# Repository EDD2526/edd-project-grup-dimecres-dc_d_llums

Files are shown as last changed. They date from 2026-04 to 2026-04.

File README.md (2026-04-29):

# Projecte Llums Cotxe

> **Autors:** Marcel Lleonart, Eric Ruiz, Josep Leyva
> **Versió:** 1.1
> **Eina de disseny:** KiCad 9.0 o superior

---

##  Objectiu

Desenvolupar un **sistema de control de llums per a un automòbil a escala de projecte**, gestionat mitjançant un microcontrolador. El sistema integra els principals subsistemes d'il·luminació d'un vehicle i permet el seu control manual i automàtic.

### Funcions principals

* Llums diürnes (**DRL**)
* Intermitents esquerre i dret
* Llums de creuament
* Llums de carretera
* Activació automàtica segons la llum ambiental

Cada canal incorpora:

* Etapa de potència amb MOSFET
* Resistència de gate i pull-down
* Control directe des del microcontrolador mitjançant GPIO

---

##  Diagrama de blocs

<p align="center">
  
</p>

---

##  Descripció funcional dels blocs

###  Microcontrolador – PIC18F26Q83

Coordina tots els subsistemes de llum, processa les entrades dels sensors i gestiona les comunicacions externes. Disposa d'interfícies **CAN**, **I2C** i **USART** per a expansió, diagnosi i depuració.

###  Driver de llums diürnes (DRL)

Controla l'encesa automàtica de les llums diürnes mitjançant un MOSFET **AO3400A**. L'activació es realitza segons la lectura del sensor de llum ambiental.

###  Driver d'intermitents

Gestiona els intermitents esquerre i dret. El parpelleig es genera per programari utilitzant temporitzadors interns del microcontrolador.

###  Driver de llums de creuament

Permet el control ON/OFF de les llums de creuament amb protecció elèctrica individual.

###  Driver de llums de carretera

Controla les llums de carretera amb protecció mitjançant fusible. Compatible amb càrregues LED o halògenes de baixa potència.

### Sensor de llum ambiental

Mesura la il·luminació exterior i permet l'activació automàtica de les llums diürnes o altres funcions programades.

---

##  Especificacions tècniques

| Paràmetre | Valor |
| --- | --- |
| Alimentació principal  | 12 Vcc |
| Alimentació lògica | 3.3 V regulats |
| Microcontrolador | Pic24hj128gp502 |
| Comunicacions | CAN, I2C, USART |
| MOSFET de potència | AO3400A (canal N, logic-level) |
| Nivell de control GPIO | 3.3 V |
| Protecció |resistència de gate + pull-down |

---

##  Assignació de GPIO

| Senyal | Funció |
| --- | --- |
| `DRL_CTRL` | Control de llums diürnes |
| `TURN_LEFT_CTRL`  | Intermitent esquerre |
| `TURN_RIGHT_CTRL` | Intermitent dret |
| `LOW_BEAM_CTRL` | Llums de creuament |
| `HI_BEAM_CTRL` | Llums de carretera |
| `LIGHT_INT` | Interrupció del sensor de llum |

---

##  Funcionalitats implementades

* Activació automàtica de les DRL segons la llum ambiental
* Control independent de llums de creuament i carretera
* Interfície de depuració per USART
* Arquitectura preparada per integració en xarxa CAN

---

##  Llista de materials (BOM)

| Component | Valor / Model | Encapsulat | Quantitat |
| --- | --- | --- | ---: |
| Microcontrolador | Pic24hj128gp502 | SOIC-28 | 1 |
| MOSFET canal N | AO3400A | SOT-23 | 8 |
| Regulador lineal | LM1117-5.0 | TO-252 | 1 |
| Resonador / Cristall | 8 MHz | HC-49 o equivalent | 1 |
| Inductor | 33 µH | Radial | 1 |
| Díodes de protecció | Rectificador | DO-201AD | 9 |
| Condensadors de desacoblament | 100 nF | 0805 | 7 |
| Condensadors | 10 µF | 0805 | 3 |
| Condensador electrolític | 680 µF | Radial | 1 |
| Condensadors | 33 pF | 0805 | 2 |
| Condensador | 4.7 nF | 0805 | 1 |
| Resistències | 100 Ω | 0805 | 8 |
| Resistències | 10 kΩ | 0805 |  Diverses |
| Borns de connexió | 2 vies, pas 5.08 mm | Terminal Block | 11 |
| Connector ICSP | Programació PIC | 2x03, 2.54 mm | 1 |
| Interruptors SPDT | Selector | Through-hole | 5 |
| Polsador | Reset / funció | 6 mm | 1 |
| Sensor de llum | TSL2561 (o equivalent I2C) | SMD | 1 |

> **Nota:** La quantitat exacta d'alguns components passius pot variar segons la revisió del disseny i les opcions de muntatge.

---

##  Programació i configuració

### Perifèrics utilitzats

* GPIO digitals per al control de sortides
* I2C per al sensor de llum
* USART per a depuració i diagnosi
* CAN per a futures ampliacions

---

##  Proteccions incorporades

* Resistència sèrie a la gate dels MOSFET
* Resistència pull-down per evitar activacions espúries
* Filtrat de l'alimentació mitjançant condensadors de desacoblament
* Protecció davant transitoris de commutació

---

##  Aplicacions

Aquest projecte és ideal per a:

* Maquetes i prototips d'automoció
* Sistemes d'il·luminació intel·ligents
* Pràctiques de microcontroladors i electrònica de potència
* Desenvolupament de mòduls electrònics per automoció

---

##  Estat del projecte

**Versió actual:** 1.5

* ✅ Esquemàtic completat
* 🔄 PCB en desenvolupament i validació
* ✔️ BOM inicial verificada

---

##  Llicència

Aquest projecte ha estat desenvolupat amb finalitats educatives i acadèmiques.

---

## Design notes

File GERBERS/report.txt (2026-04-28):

Aviso: Corrección del ancho restringida. El valor de la corrección del ancho debe encontrarse en el rango de [-0,149999 mm; -0,000002 mm] para las reglas de diseño actuales.
Plotted to 'C:\Users\User\Desktop\Grup_D_Llums-F_Cu.gbr'.
Plotted to 'C:\Users\User\Desktop\Grup_D_Llums-B_Cu.gbr'.
Plotted to 'C:\Users\User\Desktop\Grup_D_Llums-F_Paste.gbr'.
Plotted to 'C:\Users\User\Desktop\Grup_D_Llums-B_Paste.gbr'.
Plotted to 'C:\Users\User\Desktop\Grup_D_Llums-F_Silkscreen.gbr'.
Plotted to 'C:\Users\User\Desktop\Grup_D_Llums-B_Silkscreen.gbr'.
Plotted to 'C:\Users\User\Desktop\Grup_D_Llums-F_Mask.gbr'.
Plotted to 'C:\Users\User\Desktop\Grup_D_Llums-B_Mask.gbr'.
Plotted to 'C:\Users\User\Desktop\Grup_D_Llums-Edge_Cuts.gbr'.
Created Gerber job file 'C:\Users\User\Desktop\Grup_D_Llums-job.gbrjob'.
Info: Done.
Info: Done.

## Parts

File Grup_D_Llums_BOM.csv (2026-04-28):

Id | Identificador | Huella | Cantidad | Identificación | Suministrador y ref
1 | C11,C13,C10 | C_0805_2012Metric | 3 | 10 uF
2 | R17,R19,R3,R9,R2,R7,R15,R5 | R_0805_2012Metric | 8 | 100
3 | J12,J7,J6,J11,J10,J13,J8,J2,J14,J3,J9 | TerminalBlock_Phoenix_MKDS-1,5-2-5.08_1x02_P5.08mm_Horizontal | 11 | Screw_Terminal_01x02
4 | J4 | PinHeader_2x03_P2.54mm_Vertical | 1 | Conn_PIC_ICSP_ICD
5 | Q6,Q4,Q8,Q2,Q3,Q5,Q7,Q1 | SOT-23 | 8 | AO3400A
6 | C8,C6,C2,C5,C7 | C_0805_2012Metric | 5 | 100 nF
7 | L1 | L_Radial_D10.0mm_P5.00mm_Fastron_07M | 1 | 33 U
8 | C16,C4 | C_0805_2012Metric | 2 | 100nF
9 | SW2,SW6,SW4,SW5,SW3 | SW_SPDT_CK_JS102011SAQN | 5 | SW_SPDT
10 | C9 | CP_Radial_D10.0mm_P5.00mm | 1 | 680 uF
11 | Y2 | Crystal_HC49-U_Vertical | 1 | Crystal
12 | D5,D3,D7,D11,D9,D10,D6,D8,D12 | D_DO-201AD_P15.24mm_Horizontal | 9 | D
13 | SW7 | SW_PUSH_6mm | 1 | SW_SPST
14 | C14,C17 | C_0805_2012Metric | 2 | 33pF
15 | C3 | C_0805_2012Metric | 1 | 4.7 nF
16 | U7 | TO-252-3_TabPin2 | 1 | LM1117DT-3.3
17 | R8,pull_FC1,pull_INT1,R4,R18,R20,R16,R1,R14,R6,R10 | R_0805_2012Metric | 11 | 10k
18 | J1,J5 | DSUB-9_Socket_Horizontal_P2.77x2.84mm_EdgePinOffset9.40mm | 2 | DE9_Pins
19 | U9 | Rohm_RPR-0521RS | 1 | RPR-0521RS
20 | U2 | TO-263-5_TabPin3 | 1 | LM2596S-5
21 | U6 | SOIC-8_3.9x4.9mm_P1.27mm | 1 | SN65HVD232
22 | U3 | TO-220-15_P2.54x5.08mm_StaggerOdd_Lead4.58mm_Vertical | 1 | L298N
23 | D2 | LED_0805_2012Metric | 1 | LED
24 | C1 | CP_Radial_D8.0mm_P3.50mm | 1 | 220 uF
25 | pull_SCL2,pull_SDA2 | R_0805_2012Metric | 2 | 4k7
26 | R11 | R_0805_2012Metric | 1 | 1k
27 | U1 | TQFP-44_10x10mm_P0.8mm | 1 | PIC32MX250F128D-IPT
28 | R12,R13 | R_0603_1608Metric | 2 | 60 Ω
29 | SW1 | SW_Push_1P1T-SH_NO_CK_KMR2xxG | 1 | SW_Push
30 | D4,D1 | D_DO-201AD_P15.24mm_Horizontal | 2 | 1N5822

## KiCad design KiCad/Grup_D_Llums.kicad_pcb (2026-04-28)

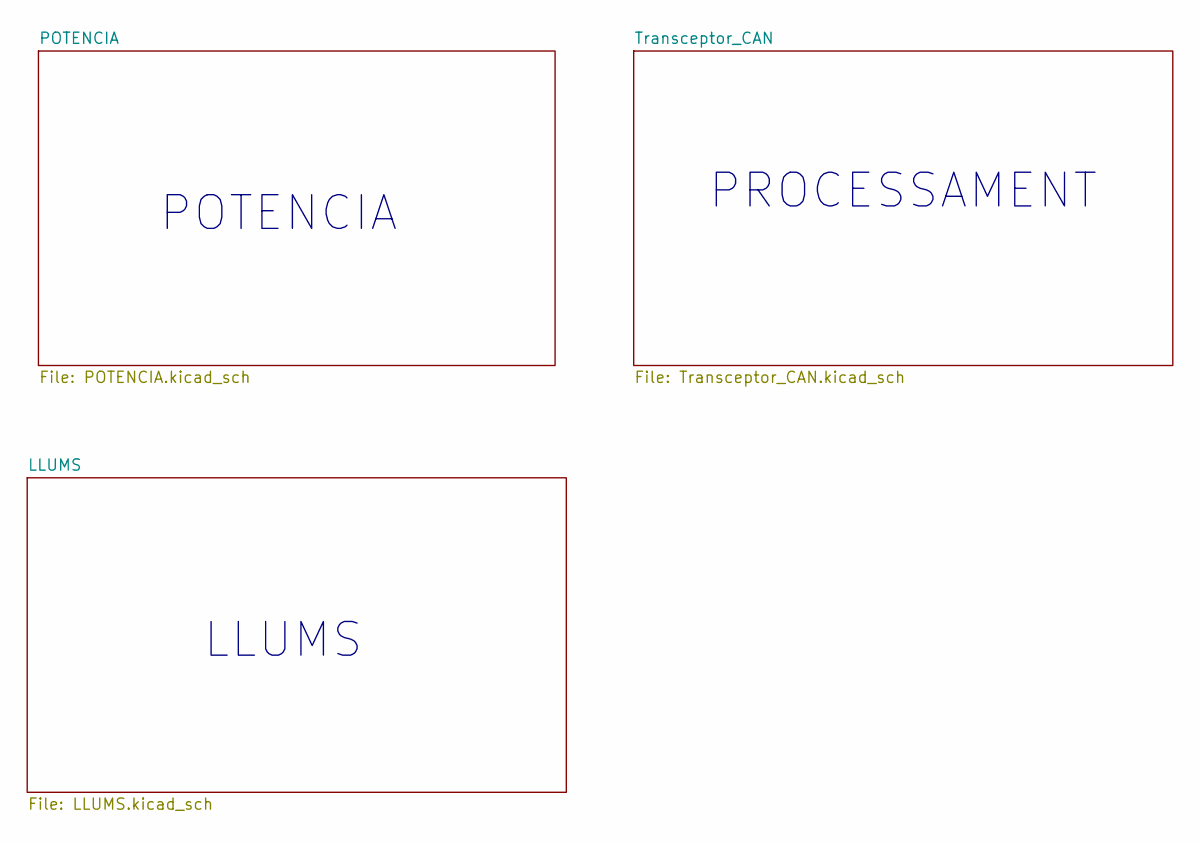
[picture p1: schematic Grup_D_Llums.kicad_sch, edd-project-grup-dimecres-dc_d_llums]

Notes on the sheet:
PROCESSAMENT
LLUMS
POTENCIA

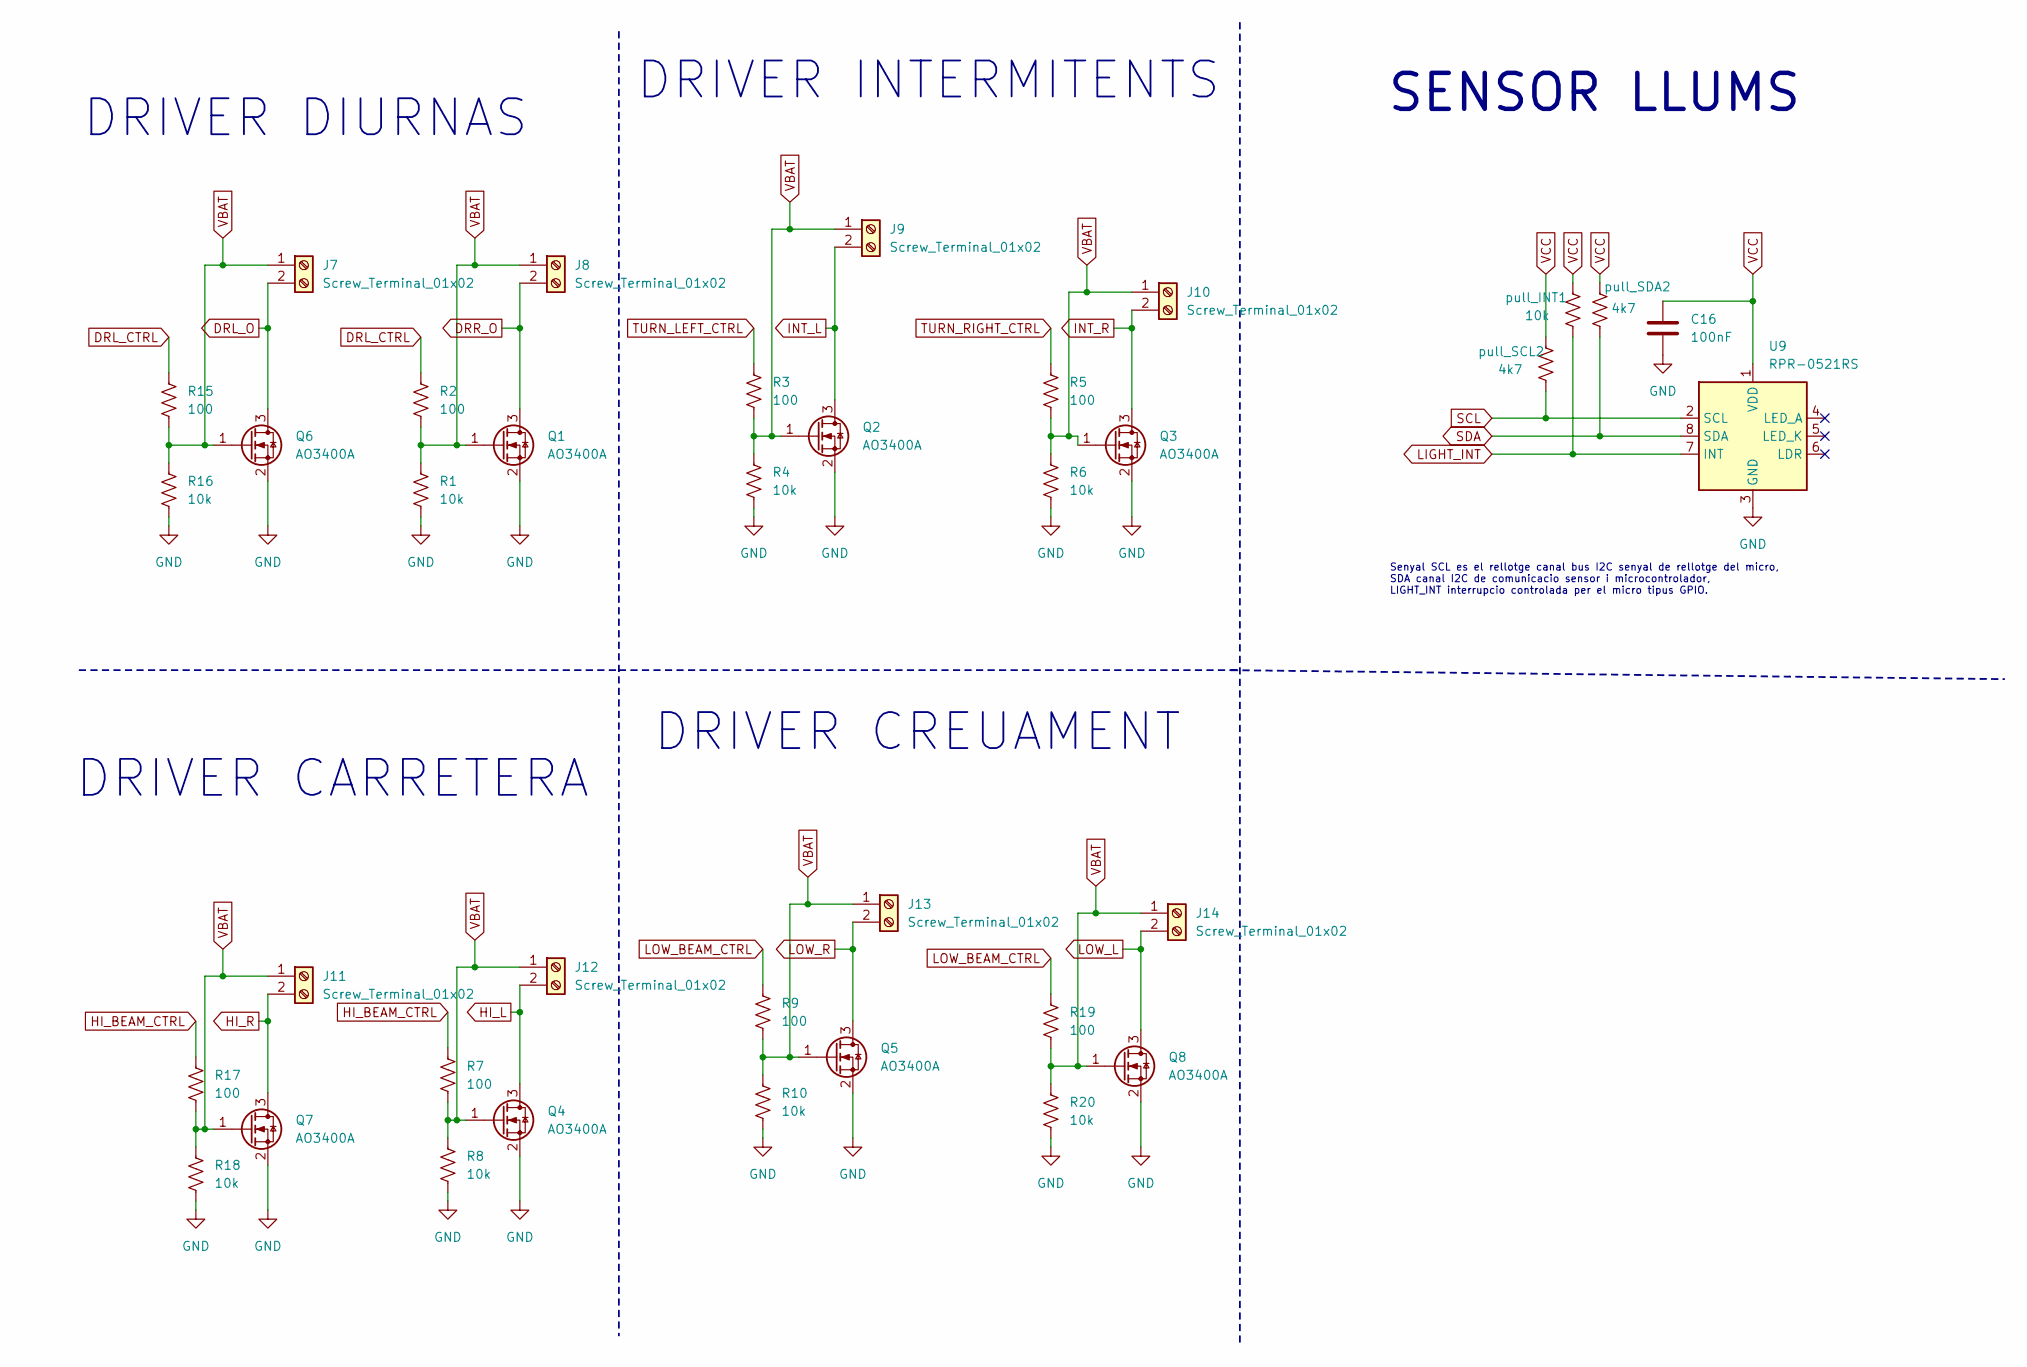
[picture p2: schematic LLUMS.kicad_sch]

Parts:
C16: 100nF; C_0805_2012Metric
J7, J8, J9, J10, J11, J12, J13, J14: Screw_Terminal_01x02; TerminalBlock_Phoenix_MKDS-1,5-2-5.08_1x02_P5.08mm_Horizont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
Q1, Q2, Q3, Q4, Q5, Q6, Q7, Q8: AO3400A; SOT-23
R1, R4, R6, R8, R10, R16, R18, R20: 10k; R_0805_2012Metric
R2, R3, R5, R7, R9, R15, R17, R19: 100; R_0805_2012Metric
U9: RPR-0521RS; Rohm_RPR-0521RS
pull_INT1: 10k; R_0805_2012Metric
pull_SCL2: 4k7; R_0805_2012Metric
pull_SDA2: 4k7; R_0805_2012Metric

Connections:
DRL_CTRL: R2.1, R15.1; also elsewhere on the board
DRL_O: J7.2, Q6.3 (D)
DRR_O: J8.2, Q1.3 (D)
GND: C16.2, Q1.2 (S), Q2.2 (S), Q3.2 (S), Q4.2 (S), Q5.2 (S), Q6.2 (S), Q7.2 (S), Q8.2 (S), R1.2, R4.2, R6.2, R8.2, R10.2, R16.2, R18.2, R20.2, U9.3 (GND); also elsewhere on the board
HI_BEAM_CTRL: R7.1, R17.1; also elsewhere on the board
HI_L: J12.2, Q4.3 (D)
HI_R: J11.2, Q7.3 (D)
INT_L: J9.2, Q2.3 (D)
INT_R: J10.2, Q3.3 (D)
LIGHT_INT: U9.7 (INT), pull_INT1.2; also elsewhere on the board
LOW_BEAM_CTRL: R9.1, R19.1; also elsewhere on the board
LOW_L: J14.2, Q8.3 (D)
LOW_R: J13.2, Q5.3 (D)
SCL: U9.2 (SCL), pull_SCL2.2; also elsewhere on the board
SDA: U9.8 (SDA), pull_SDA2.2; also elsewhere on the board
TURN_LEFT_CTRL: R3.1; also elsewhere on the board
TURN_RIGHT_CTRL: R5.1; also elsewhere on the board
VBAT: J7.1, J8.1, J9.1, J10.1, J11.1, J12.1, J13.1, J14.1, Q1.1 (G), Q2.1 (G), Q3.1 (G), Q4.1 (G), Q5.1 (G), Q6.1 (G), Q7.1 (G), Q8.1 (G), R1.1, R2.2, R3.2, R4.1, R5.2, R6.1, R7.2, R8.1, R9.2, R10.1, R15.2, R16.1, R17.2, R18.1, R19.2, R20.1; also elsewhere on the board
VCC: C16.1, U9.1 (VDD), pull_INT1.1, pull_SCL2.1, pull_SDA2.1; also elsewhere on the board

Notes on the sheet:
DRIVER INTERMITENTS
SENSOR LLUMS
DRIVER CREUAMENT
DRIVER DIURNAS
DRIVER CARRETERA
Senyal SCL es el rellotge canal bus I2C senyal de rellotge del micro, SDA canal I2C de comunicacio sensor i microcontrolador, LIGHT_INT interrupcio controlada per el micro tipus GPIO.

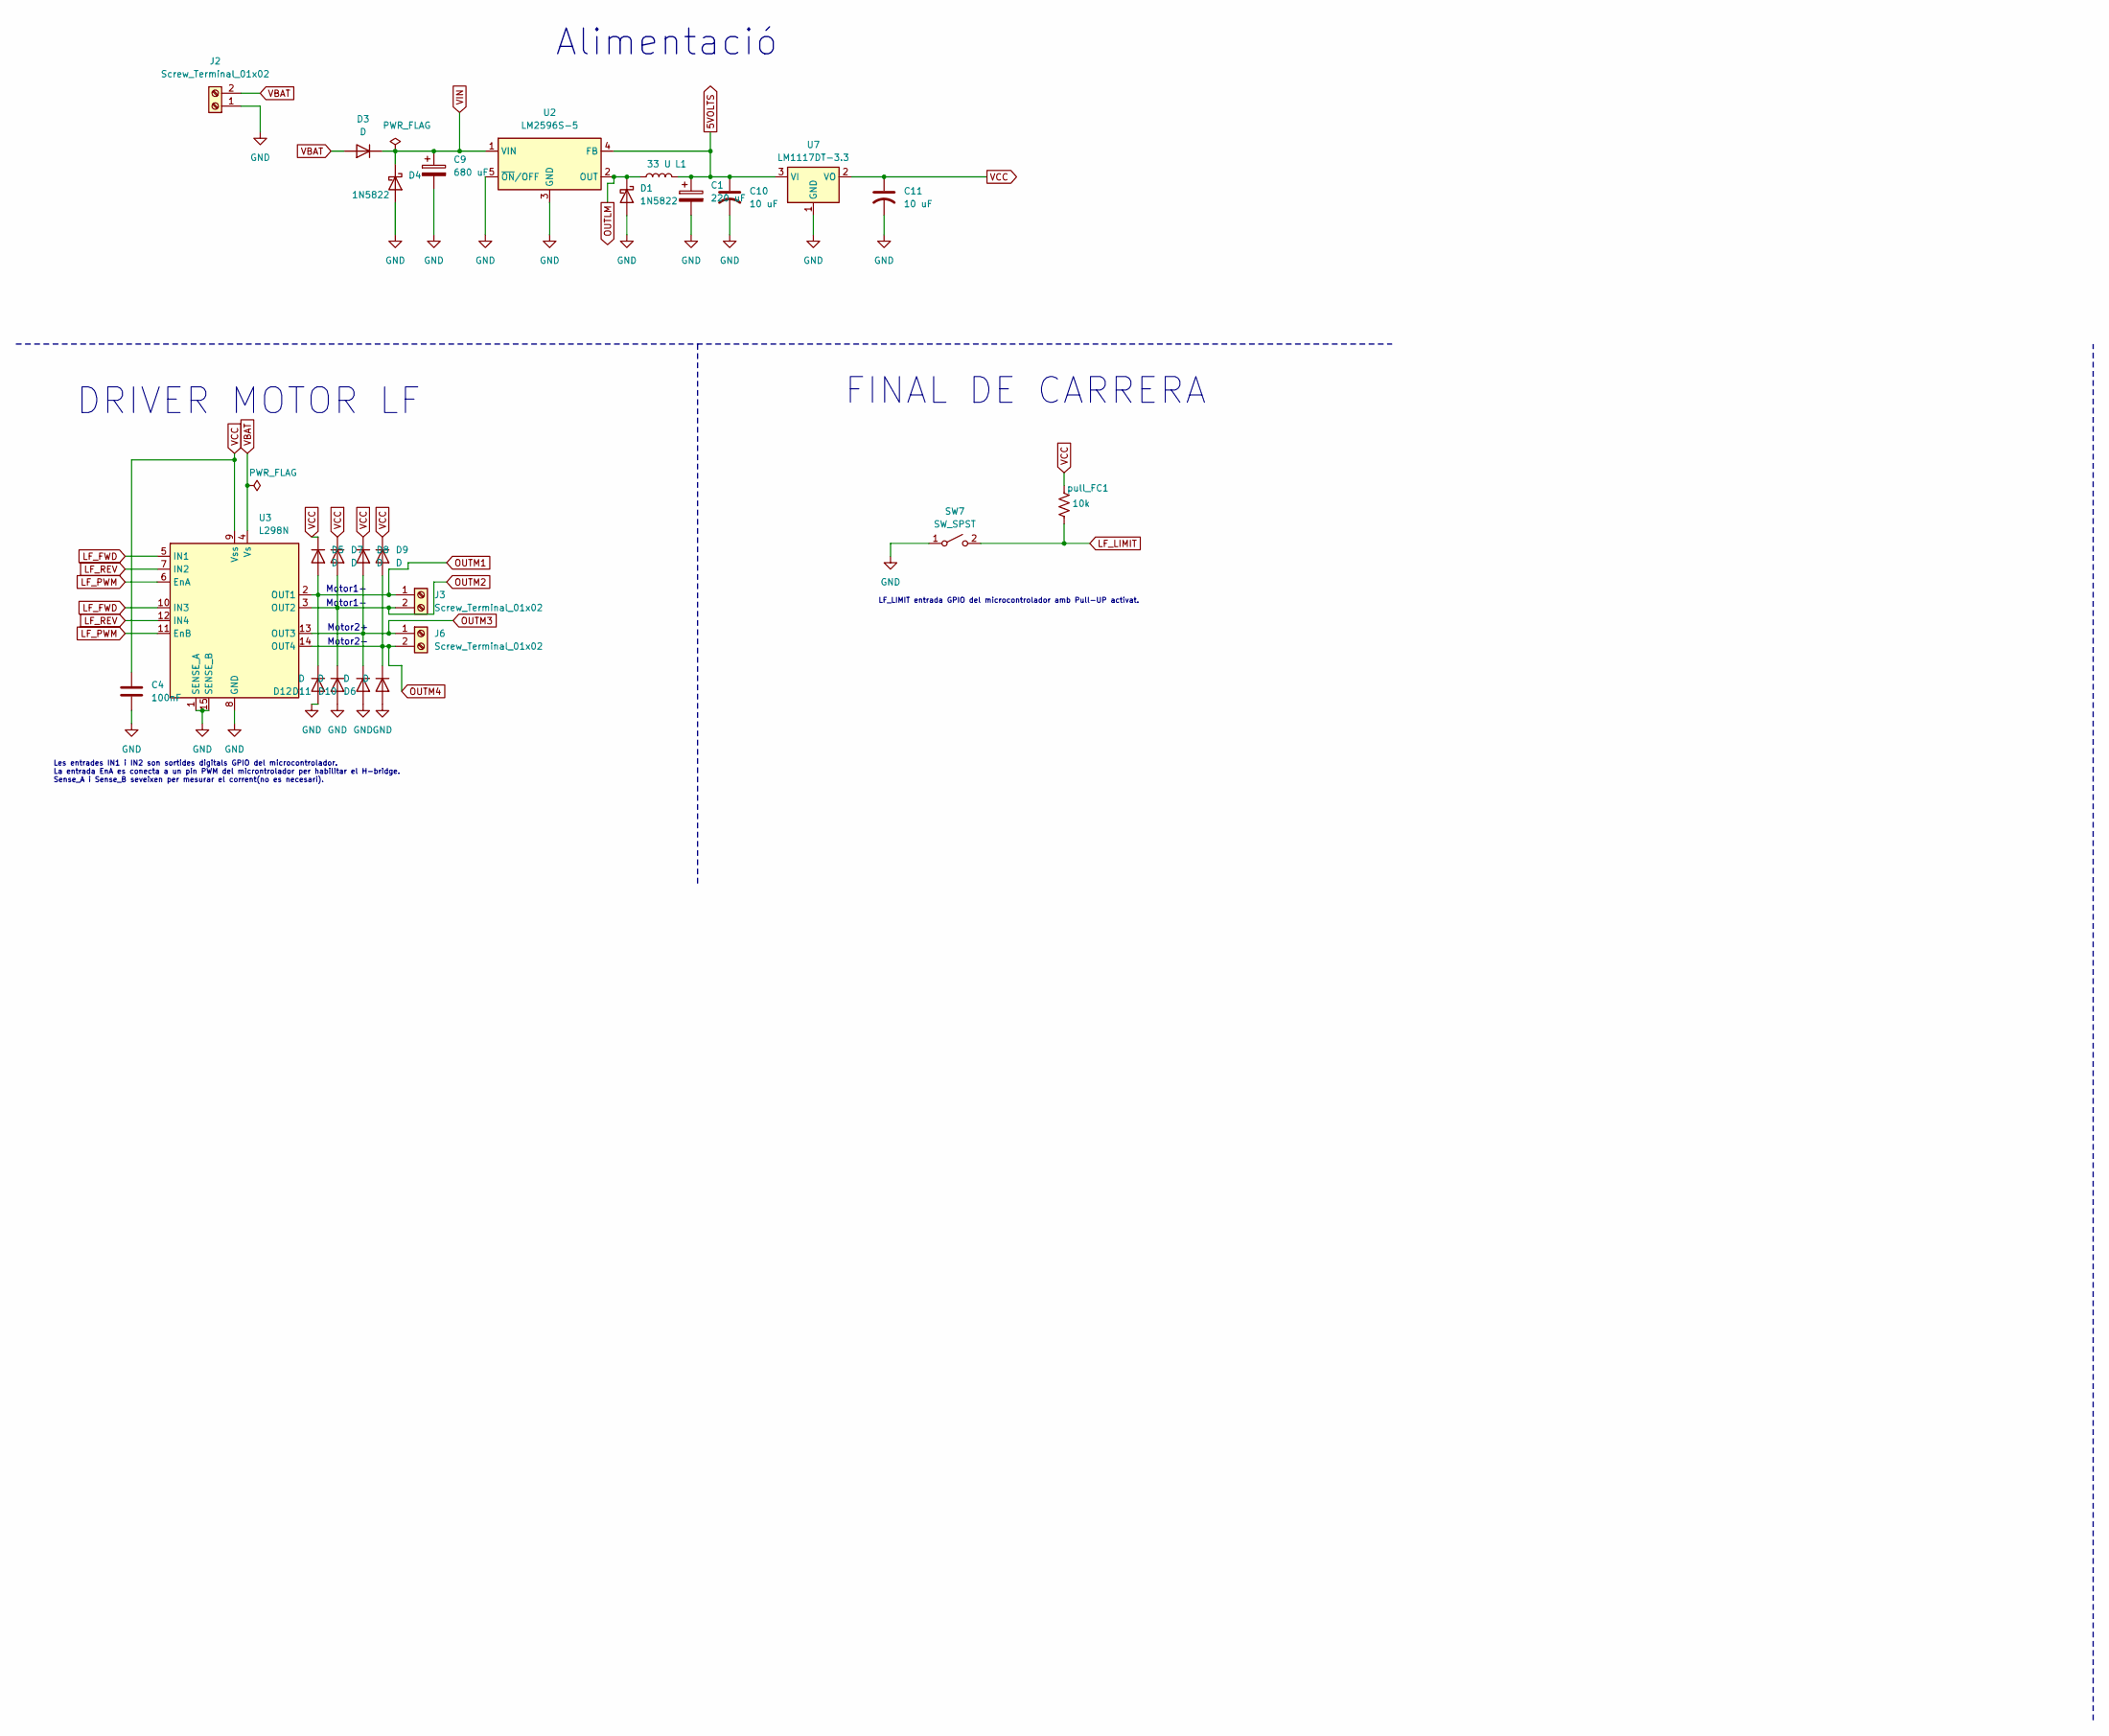
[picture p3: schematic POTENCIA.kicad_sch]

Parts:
C1: 220 uF; CP_Radial_D8.0mm_P3.50mm
C4: 100nF; C_0805_2012Metric
C9: 680 uF; CP_Radial_D10.0mm_P5.00mm
C10, C11: 10 uF; C_0805_2012Metric
D1, D4: 1N5822; D_DO-201AD_P15.24mm_Horizontal
D3, D5, D6, D7, D8, D9, D10, D11, D12: D; D_DO-201AD_P15.24mm_Horizontal
J2, J3, J6: Screw_Terminal_01x02; TerminalBlock_Phoenix_MKDS-1,5-2-5.08_1x02_P5.08mm_Horizont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
L1: 33 U; L_Radial_D10.0mm_P5.00mm_Fastron_07M
SW7: SW_SPST; SW_PUSH_6mm
U2: LM2596S-5; TO-263-5_TabPin3
U3: L298N; TO-220-15_P2.54x5.08mm_StaggerOdd_Lead4.58mm_Vertical
U7: LM1117DT-3.3; TO-252-3_TabPin2
pull_FC1: 10k; R_0805_2012Metric

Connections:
5VOLTS: C1.1, C10.1, L1.2, U2.4 (FB), U7.3 (VI)
GND: C1.2, C4.2, C9.2, C10.2, C11.2, D1.2 (A), D4.2 (A), D6.2 (A), D10.2 (A), D11.2 (A), D12.2 (A), J2.1, SW7.1 (A), U2.3 (GND), U2.5 (~ON/OFF), U3.1 (SENSE_A), U3.8 (GND), U3.15 (SENSE_B), U7.1 (GND); also elsewhere on the board
LF_FWD: U3.5 (IN1), U3.10 (IN3); also elsewhere on the board
LF_LIMIT: SW7.2 (B), pull_FC1.2; also elsewhere on the board
LF_PWM: U3.6 (EnA), U3.11 (EnB); also elsewhere on the board
LF_REV: U3.7 (IN2), U3.12 (IN4); also elsewhere on the board
OUTLM: D1.1 (K), L1.1, U2.2 (OUT)
OUTM1: D5.2 (A), D12.1 (K), J3.1, U3.2 (OUT1)
OUTM2: D7.2 (A), D11.1 (K), J3.2, U3.3 (OUT2)
OUTM3: D8.2 (A), D10.1 (K), J6.1, U3.13 (OUT3)
OUTM4: D6.1 (K), D9.2 (A), J6.2, U3.14 (OUT4)
VBAT: D3.2 (A), J2.2, U3.4 (Vs); also elsewhere on the board
VCC: C4.1, C11.1, D5.1 (K), D7.1 (K), D8.1 (K), D9.1 (K), U3.9 (Vss), U7.2 (VO), pull_FC1.1; also elsewhere on the board
VIN: C9.1, D3.1 (K), D4.1 (K), U2.1 (VIN)

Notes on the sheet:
Les entrades IN1 i IN2 son sortides digitals GPIO del microcontrolador. La entrada EnA es conecta a un pin PWM del microntrolador per habilitar el H-bridge. Sense_A i Sense_B seveixen per mesurar el corrent(no es necesari).
Alimentació
Motor2-
FINAL DE CARRERA
Motor1+
Motor2+
DRIVER MOTOR LF
Motor1-
LF_LIMIT entrada GPIO del microcontrolador amb Pull-UP activat.

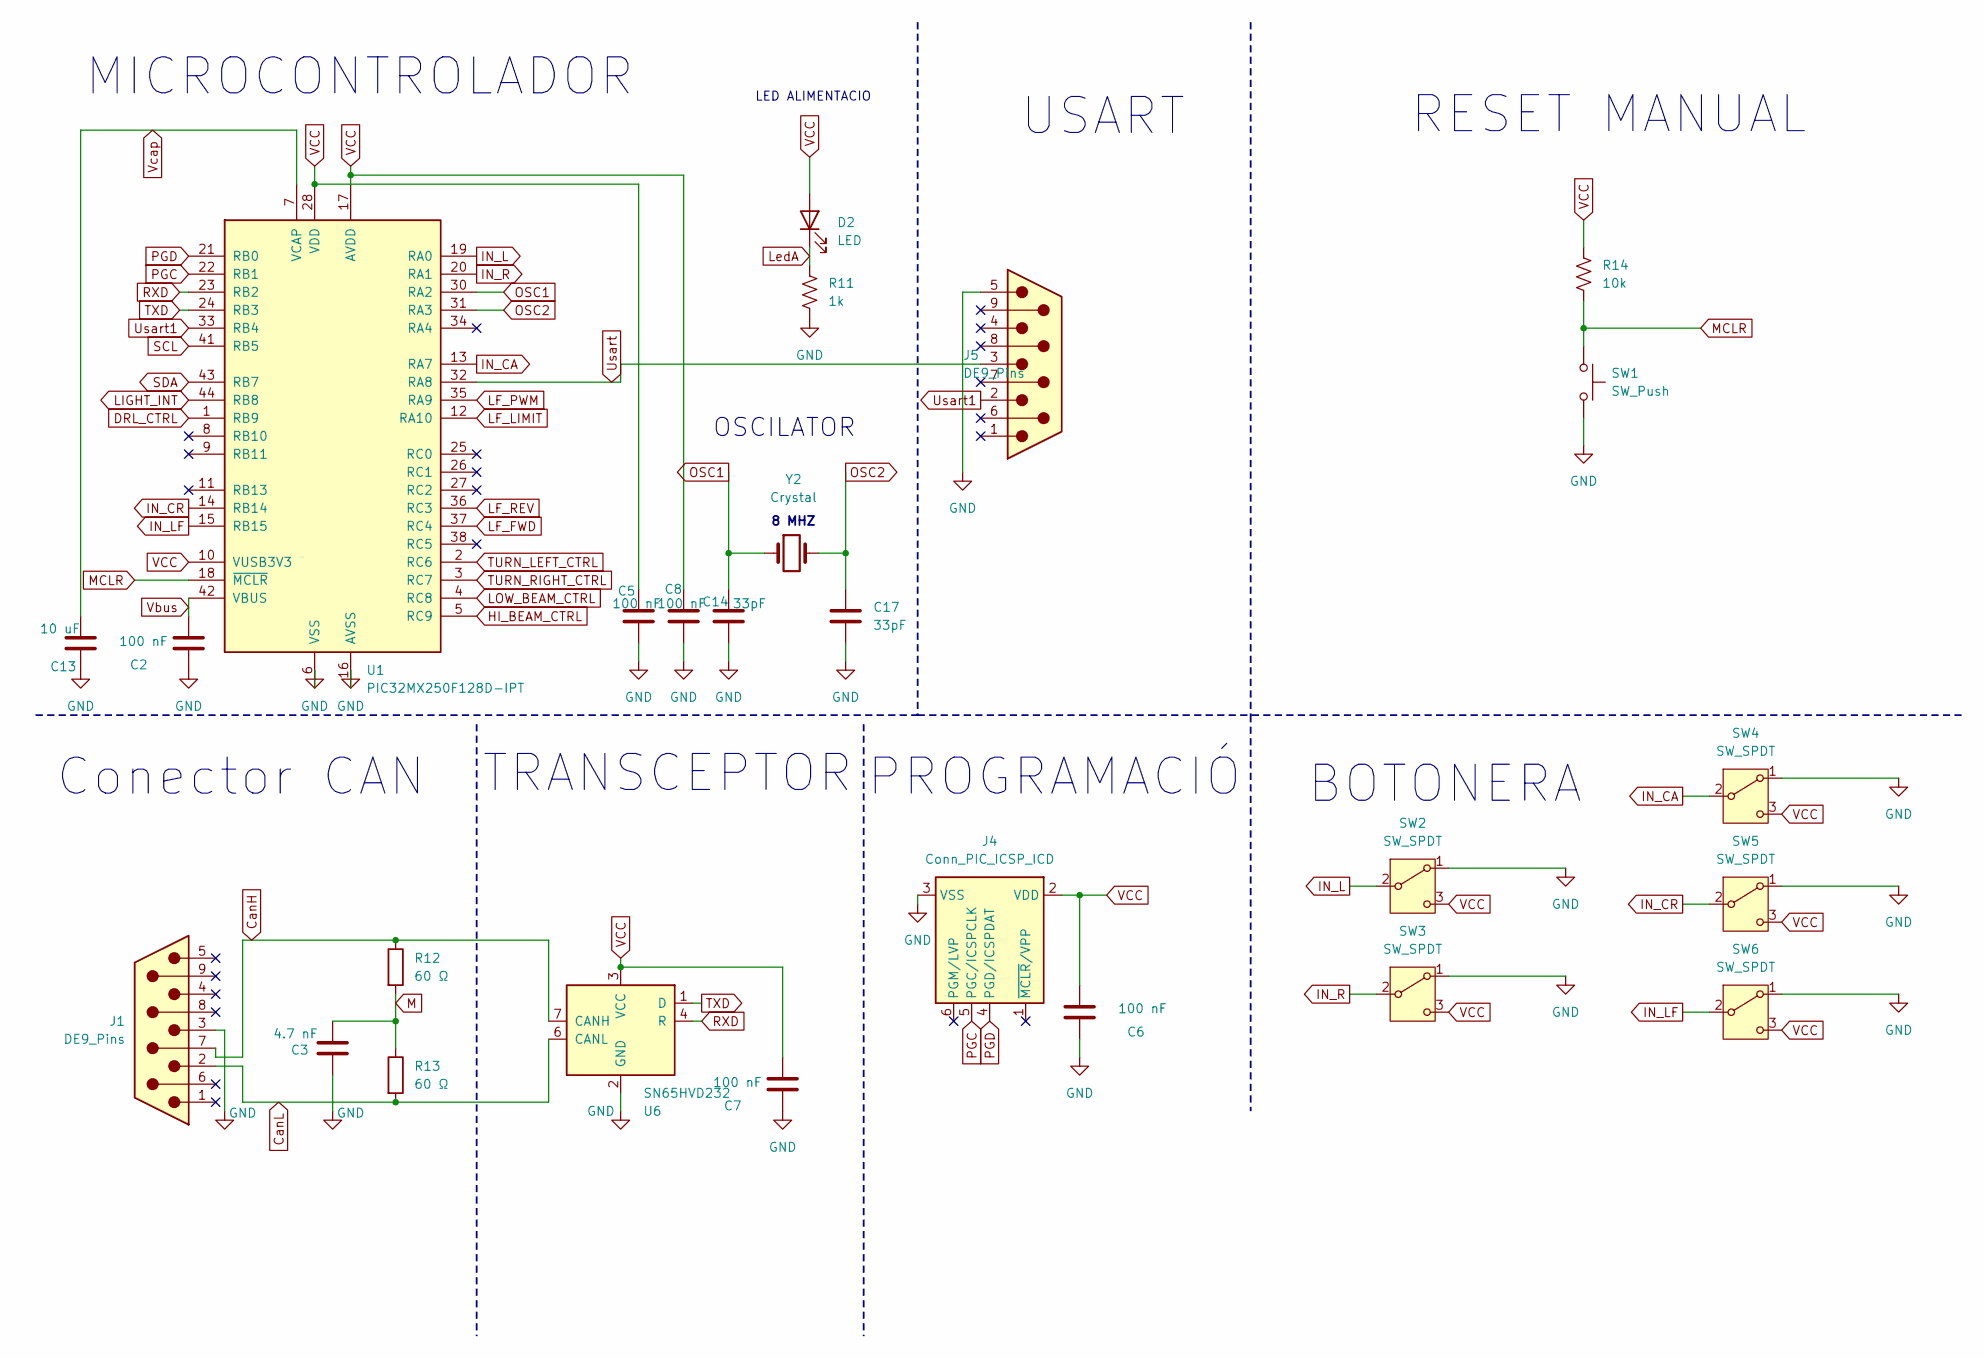
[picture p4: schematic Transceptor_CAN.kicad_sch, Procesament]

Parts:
C2, C5, C6, C7, C8: 100 nF; C_0805_2012Metric
C3: 4.7 nF; C_0805_2012Metric
C13: 10 uF; C_0805_2012Metric
C14, C17: 33pF; C_0805_2012Metric
D2: LED; LED_0805_2012Metric_Pad1.15x1.40mm_HandSolder
J1, J5: DE9_Pins; DSUB-9_Socket_Horizontal_P2.77x2.84mm_EdgePinOffset9.40mm
J4: Conn_PIC_ICSP_ICD; PinHeader_2x03_P2.54mm_Vertical
R11: 1k; R_0805_2012Metric
R12, R13: 60 Ω; R_0603_1608Metric
R14: 10k; R_0805_2012Metric
SW1: SW_Push; SW_Push_1P1T-SH_NO_CK_KMR2xxG
SW2, SW3, SW4, SW5, SW6: SW_SPDT; SW_SPDT_CK_JS102011SAQN
U1: PIC32MX250F128D-IPT; TQFP-44_10x10mm_P0.8mm
U6: SN65HVD232; SOIC-8_3.9x4.9mm_P1.27mm
Y2: Crystal; Crystal_HC49-U_Vertical

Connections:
CanH: J1.7, R12.1, U6.7 (CANH)
CanL: J1.2, R13.2, U6.6 (CANL)
DRL_CTRL: U1.1 (RB9); also elsewhere on the board
GND: C2.2, C3.1, C5.2, C6.2, C7.2, C8.2, C13.1, C14.2, C17.2, J1.3, J4.3 (VSS), J5.5, R11.2, SW1.2, SW2.1 (A), SW3.1 (A), SW4.1 (A), SW5.1 (A), SW6.1 (A), U1.6 (VSS), U1.16 (AVSS), U1.29 (VSS), U1.39 (VSS), U6.2 (GND); also elsewhere on the board
HI_BEAM_CTRL: U1.5 (RC9); also elsewhere on the board
IN_CA: SW4.2 (B), U1.13 (RA7)
IN_CR: SW5.2 (B), U1.14 (RB14)
IN_L: SW2.2 (B), U1.19 (RA0)
IN_LF: SW6.2 (B), U1.15 (RB15)
IN_R: SW3.2 (B), U1.20 (RA1)
LF_FWD: U1.37 (RC4); also elsewhere on the board
LF_LIMIT: U1.12 (RA10); also elsewhere on the board
LF_PWM: U1.35 (RA9); also elsewhere on the board
LF_REV: U1.36 (RC3); also elsewhere on the board
LIGHT_INT: U1.44 (RB8); also elsewhere on the board
LOW_BEAM_CTRL: U1.4 (RC8); also elsewhere on the board
LedA: D2.1 (K), R11.1
M: C3.2, R12.2, R13.1
MCLR: R14.2, SW1.1, U1.18 (~MCLR)
OSC1: C14.1, U1.30 (RA2), Y2.1
OSC2: C17.1, U1.31 (RA3), Y2.2
PGC: J4.5 (PGC/ICSPCLK), U1.22 (RB1)
PGD: J4.4 (PGD/ICSPDAT), U1.21 (RB0)
RXD: U1.23 (RB2), U6.4 (R)
SCL: U1.41 (RB5); also elsewhere on the board
SDA: U1.43 (RB7); also elsewhere on the board
TURN_LEFT_CTRL: U1.2 (RC6); also elsewhere on the board
TURN_RIGHT_CTRL: U1.3 (RC7); also elsewhere on the board
TXD: U1.24 (RB3), U6.1 (D)
Usart: J5.3, U1.32 (RA8)
Usart1: J5.2, U1.33 (RB4)
VCC: C5.1, C6.1, C7.1, C8.1, D2.2 (A), J4.2 (VDD), R14.1, SW2.3 (C), SW3.3 (C), SW4.3 (C), SW5.3 (C), SW6.3 (C), U1.10 (VUSB3V3), U1.17 (AVDD), U1.28 (VDD), U1.40 (VDD), U6.3 (VCC); also elsewhere on the board
Vbus: C2.1, U1.42 (VBUS)
Vcap: C13.2, U1.7 (VCAP)

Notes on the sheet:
MICROCONTROLADOR
PROGRAMACIÓ
BOTONERA
8 MHZ
USART
RESET MANUAL
Conector CAN
TRANSCEPTOR
OSCILATOR
LED ALIMENTACIO

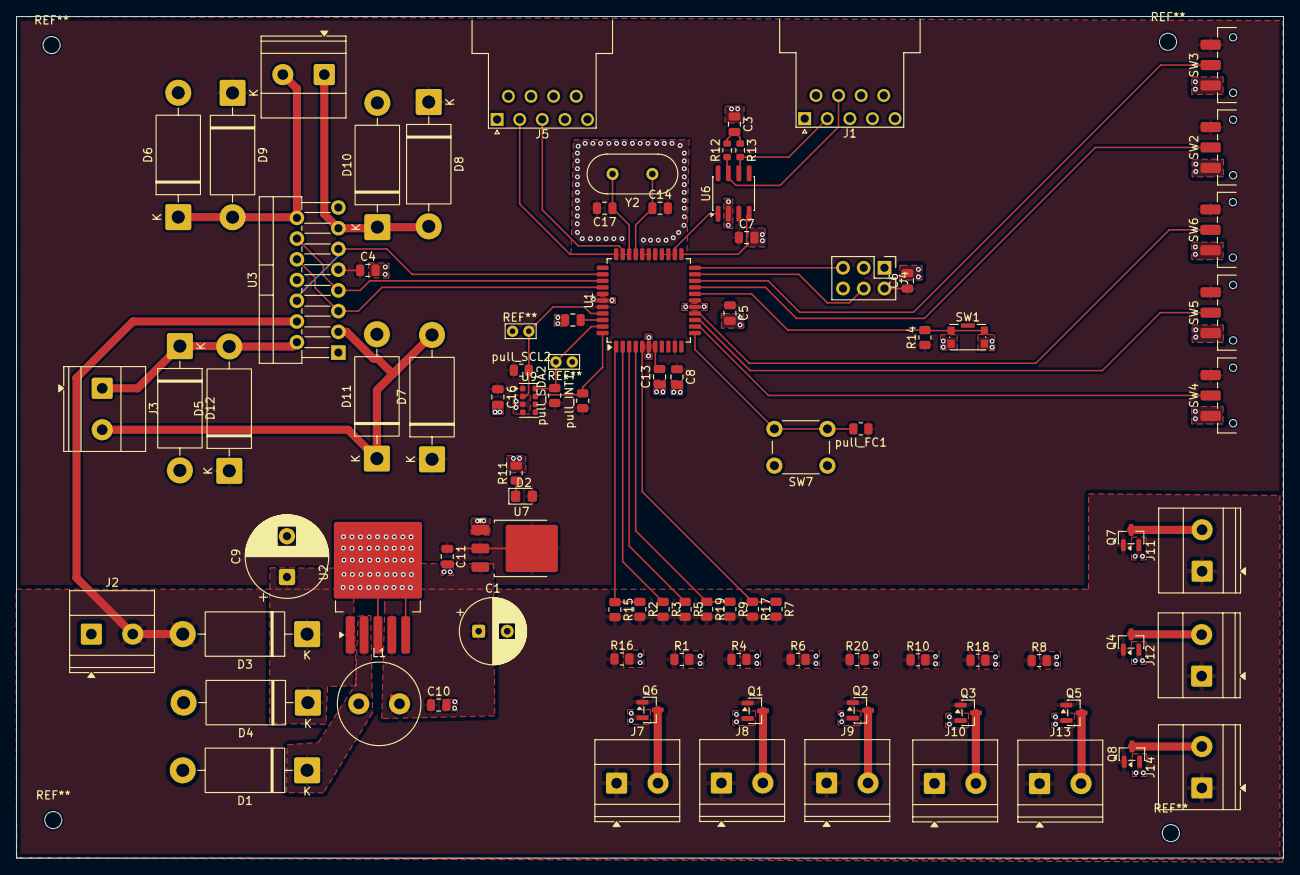
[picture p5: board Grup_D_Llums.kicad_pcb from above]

Board: 2 copper layers, 155.3 x 103.2 mm, 88 parts (0 on the bottom side), 50 nets.

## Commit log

2026-03-11 Projecte kicad creat
    [Grup_D_Llums.kicad_pcb, Grup_D_Llums.kicad_sch]
2026-03-16 Raiz main creada
    [Grup_D_Llums.kicad_sch, Sheet_a.kicad_sch, Sheet_b.kicad_sch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]
2026-03-16 Deleted useless documents
    [Sheet_d_c.kicad_sch, Sheet_e_c.kicad_sch, Sheet_f_c.kicad_sch]
2026-03-16 Implementacio Drivers Motor Neteja fars
    [Drivers_motor.kicad_sch, Grup_D_Llums.kicad_sch, Sheet_a.kicad_sch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]
2026-03-16 Transceptor CAN 1
    [Sheet_b.kicad_sch, Sheet_d_c.kicad_sch, Sheet_e_c.kicad_sch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]
2026-03-16 Solucionando problemas del esquematic
    [Alimentacio.kicad_sch, Grup_D_Llums.kicad_sch, Sheet_b.kicad_sch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]
2026-03-17 Carpeta de Datasheets para tener acceso rapido a la informacion de cada componente
2026-03-17 Prova 2
    [Sheet_d_c.kicad_sch, Sheet_e_c.kicad_sch, Sheet_f_c.kicad_sch]
2026-03-17 Arreglando cosas
    [Grup_D_Llums.kicad_sch, Sheet_d.kicad_sch, Sheet_d_c.kicad_sch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]
2026-03-17 Capacitat DC/DC
    [Alimentacio.kicad_sch]
2026-03-17 Sensor llums afegit
    [Alimentacio.kicad_sch, Grup_D_Llums.kicad_sch, Sensor_Llums.kicad_sch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]
2026-03-17 Driver Diurna hecho
2026-03-17 Microchip afegit
    [Sheet_f.kicad_sch]
2026-03-17 Driver llums fet
    [Drivers_Llums.kicad_sch]
2026-03-17 Communicacio afegida
    [Communicacio.kicad_sch, Grup_D_Llums.kicad_sch]
2026-03-17 Procesament i comunicació
    [Communicacio.kicad_sch, Grup_D_Llums.kicad_sch, Procesament.kicad_sch]
2026-03-17 botonera, datashet usart
    [Communicacio.kicad_sch]
2026-03-17 Update README.md
    Diagrama de bloc
2026-03-18 acabar can, estil y micro biel
    [Alimentacio.kicad_sch, Communicacio.kicad_sch, Drivers_Llums.kicad_sch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]
2026-03-23 Alimentació arreglada
    [Alimentacio.kicad_sch]
2026-03-23 Arreglat errors de schematic version 1
    [Alimentacio.kicad_sch, Drivers_Llums.kicad_sch, Drivers_motor.kicad_sch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]
2026-03-23 Pequeño error
    [POTENCIA.kicad_sch]
2026-03-23 frecuencia del reloj
    [Procesament.kicad_sch]
2026-03-25 Bloc processament
    [Grup_D_Llums.kicad_sch, POTENCIA.kicad_sch, Transceptor_CAN.kicad_sch]
2026-04-05 lil hotfix
    [Transceptor_CAN.kicad_sch]
2026-04-05 Hotfix for driver leds
    [LLUMS.kicad_sch, Transceptor_CAN.kicad_sch]
2026-04-06 Pulsador Reset manual
    [Transceptor_CAN.kicad_sch]
2026-04-06 Some placement
    [Grup_D_Llums.kicad_pcb]
2026-04-08 PCB Hotfixes
    [Grup_D_Llums.kicad_pcb]
2026-04-14 B, ground
    [Grup_D_Llums.kicad_pcb]
2026-04-14 grund c
    [Grup_D_Llums.kicad_pcb]
2026-04-15 PCB FIXIng
    [Grup_D_Llums.kicad_pcb]
